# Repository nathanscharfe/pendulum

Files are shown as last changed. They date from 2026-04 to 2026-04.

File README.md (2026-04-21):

# Inverted Pendulum Optimal Control Demonstration

This project is a successful real-hardware optimal control demonstration for an inverted pendulum mounted to a linear actuator. The repository now includes hardware, modeling, firmware, host-side control software, and experimental results for repeatable upright balancing with an LQR-based controller.

The project was inspired by my `ASE 381P-3 Optimal Control` class with Dr. Bakolas at The University of Texas at Austin.

## Upright Balance Video

Watch on YouTube:

- https://youtu.be/KnxtTf5F7fo

Local fallback:

<video src="docs/media/upright_balance_run_2026-04-21.mp4" controls muted playsinline></video>

If your Markdown viewer does not render embedded video, open:

- `docs/media/upright_balance_run_2026-04-21.mp4`

This clip shows the current successful upright controller balancing the pendulum on real hardware.

## Run The Upright Control Test

From the repository root, run:

```powershell
python -m software.host.main --actuator-port COM6 --limits-port COM10 --encoder-port COM8 control-up
```

Or open the new UI workflow:

```powershell
python -m software.host.main control-up-ui
```

What to expect:

1. The cart homes left and then moves to the middle.
2. A staging prompt appears so you can operate the latch servo on Arduino #2:
   - `p` holds the pendulum with the servo at `80 deg`
   - `g` releases the servo to `0 deg`
   - `start` zeroes the encoder, sends `g`, and begins automatic control
3. Use the staging loop until the pendulum is aligned the way you want.
4. Type `start` to begin automatic control.
5. Keep clear and be ready to stop the run if needed.

Important notes:

- The angle at the moment you type `start` becomes the controller's zero reference, so careful manual alignment still matters.
- The current upright setup uses a latch servo on Arduino #2 (`D7`) so the pendulum can be staged before release.
- The repeatably working upright setup currently uses the default Python LQR upright settings with:
  - `pendulum-length-m = 0.50`
  - `Q = diag([1, 0.1, 50, 1])`
  - `R = 1`
- The most recent saved successful run is:
  - `hardware/control experiments/upright/successful_repeatable_upright_balance_20260421_113304.csv`
- The measured no-stall actuator ceiling was about `315 mm/s`, and the current upright default speed clamp is now `350 mm/s` for experimental testing.
- Output logs are written under `hardware/control experiments/upright/`.
- Analysis notebook: `hardware/control experiments/analysis/analyze_upright_control.ipynb`
- Each upright and downward control CSV now records the full run configuration, including `lqr_mode`, pendulum length, `Q`, `R`, resolved gains, clamps, estimator settings, trigger thresholds, and sign conventions as `config_*` columns.

## Run A Pendulum Period Test

From the repository root, run:

```powershell
python -m software.host.main --encoder-port COM8 period-test
```

What to expect:

1. The host opens the encoder serial port and tells you where the CSV will be written.
2. With the pendulum hanging motionless, press Enter to zero the resting angle and start recording.
3. Pull the pendulum back by a small angle and release it.
4. Let it swing freely for several periods.
5. Press Enter again to stop and save the CSV under `hardware/magnetic encoder/captures/`.

The resulting file includes both a host timestamp (`host_timestamp_s`) and the encoder board timestamp (`time_ms`) for each sample so the free-swing period can be estimated later from the logged angle trace. New captures are named `pendulum 1_period_test_*.csv`.

Analysis notebook:

- `hardware/magnetic encoder/analysis/analyze_pendulum_1_period_test.ipynb`

Current pendulum-1 validation result:

- Capture: `hardware/magnetic encoder/captures/pendulum 1_period_test_20260419_093442.csv`
- Average measured period: about `1.42 s`
- Simple-pendulum effective length estimate: about `0.50 m`
- This supports using an effective simple-pendulum length on the order of `0.50 m` for the current host-side control defaults.

## Project Goals

- Model the pendulum and linear actuator system.
- Identify useful system parameters from measurement and calibration data.
- Design an LQR controller for the linearized pendulum dynamics.
- Implement the control loop using a software interface such as LabVIEW, Python, MATLAB, or another suitable tool.
- Use an Arduino as the interface between the control software and the physical hardware.
- Compare real hardware behavior against the model and controller predictions.

## Hardware

Current bench hardware includes:

- Pendulum
- Linear actuator
- Arduino #1 for linear actuator stepper control
- Arduino #2 for optical actuator limit sensors
- Arduino #3 for AS5600 magnetic encoder angle sensing
- Position and/or angle sensors
- Computer running LabVIEW

Current hardware-related files:

- `docs/images/assembled_pendulum_bench_setup_2026-04-17.jpg`
- `hardware/linear actuator calibration/calibration_procedure.md`
- `hardware/linear actuator calibration/linear actuator speed calibration.xlsx`
- `hardware/linear actuator calibration/actuator_speed_fit.ipynb`
- `hardware/linear actuator calibration/host_travel_calibration_20260417_194546.csv`
- `hardware/linear actuator calibration/host_travel_calibration_results.md`
- `hardware/linear actuator calibration/calibrate_linear_actuator/calibrate_linear_actuator.ino`
- `hardware/linear actuator control/linear_actuator_controller/linear_actuator_controller.ino`
- `hardware/limit sensors/limit_sensor_reader/limit_sensor_reader.ino`
- `hardware/limit sensors/servo_angle_test/servo_angle_test.ino`
- `hardware/magnetic encoder/as5600_example/README.md`
- `hardware/magnetic encoder/pendulum_angle_reader/pendulum_angle_reader.ino`
- `hardware/cad/stl/arduino mount.stl`
- `hardware/cad/stl/bearing mount.stl`
- `hardware/cad/stl/encoder mount.stl`
- `hardware/cad/stl/pendulum hinge.stl`
- `hardware/cad/stl/weight attachment.stl`
- `hardware/cad/stl/weight attachment - threaded.stl`
- `hardware/cad/reference/linear actuator stage holes.jpg`

Current modeling and control files:

- `modeling/pendulum_actuator_derivation/README.md`
- `modeling/pendulum_actuator_derivation/docs/parameters.md`
- `modeling/pendulum_actuator_derivation/docs/inverted pendulum derivation.pdf`
- `modeling/pendulum_actuator_derivation/docs/torque_diagram.svg`
- `modeling/pendulum_actuator_derivation/scripts/lqr_first_pass.m`
- `modeling/pendulum_actuator_derivation/scripts/lqr_downward_first_pass.m`
- `modeling/pendulum_actuator_derivation/scripts/lqr_upright_length_qr_sweep.m`
- `modeling/pendulum_actuator_derivation/results/upright_first_pass/lqr_first_pass_results.md`
- `modeling/pendulum_actuator_derivation/results/upright_first_pass/LQR_closed_loop_response.fig`
- `modeling/pendulum_actuator_derivation/results/upright_first_pass/LQR_closed_loop_response.png`
- `modeling/pendulum_actuator_derivation/results/downward_first_pass/lqr_downward_first_pass_results.md`
- `modeling/pendulum_actuator_derivation/results/upright_length_qr_sweep/lqr_upright_length_qr_sweep_summary.csv`

Current host software files:

- `software/host/README.md`
- `software/host/requirements.txt`
- `software/host/main.py`
- `software/host/serial_worker.py`
- `software/host/arduino_actuator.py`
- `software/host/arduino_limits.py`
- `software/host/arduino_encoder.py`
- `software/host/motion_control.py`
- `software/host/travel_calibration.py`

The linear actuator calibration notebook fits the measured actuator data and gives a command equation for converting desired speed into the required delay:

```text
delay = 58399.75215056 / (speed + 0.00022846) - 3.82116746
```

The host-side travel calibration uses the measured raw-step travel scale:

```text
steps_per_mm = 10.652
position_mm = position_steps / 10.652
target_steps = round(target_mm * 10.652)
```

3D-printable solid model exports should go in:

- `hardware/cad/stl/`

Editable CAD source files, if used, should go in:

- `hardware/cad/source/`

CAD reference photos and measurements should go in:

- `hardware/cad/reference/`

## Software

Planned software stack:

- LabVIEW, Python, MATLAB, or another suitable tool for the main control interface and experiment workflow
- Arduino firmware split across three boards: actuator motion, limit sensors, and magnetic encoder sensing
- MATLAB, Python, or similar tools for modeling, simulation, and LQR design as needed

## Control Approach

The initial controller will be based on Linear Quadratic Regulator (LQR) design. The expected workflow is:

1. Derive or identify the system dynamics.
2. Linearize the model around the operating point of interest.
3. Choose state and input cost matrices.
4. Compute the LQR gain.
5. Test the controller in simulation.
6. Implement the controller through LabVIEW and Arduino.
7. Tune and validate on the physical system.

## Repository Structure

This repository is still being organized. A likely structure is:

```text
.
+-- hardware/
|   +-- cad/
|   |   +-- reference/  # CAD reference photos and measurements
|   |   +-- source/  # Editable CAD files
|   |   `-- stl/     # 3D-printable STL exports
|   +-- linear actuator calibration/
|   |   +-- actuator_speed_fit.ipynb
|   |   +-- calibration_procedure.md
|   |   +-- linear actuator speed calibration.xlsx
|   |   `-- calibrate_linear_actuator/
|   |       `-- calibrate_linear_actuator.ino
|   +-- linear actuator control/
|   |   `-- linear_actuator_controller/
|   |       +-- README.md
|   |       `-- linear_actuator_controller.ino
|   +-- limit sensors/
|   |   `-- limit_sensor_reader/
|   |       +-- README.md
|   |       `-- limit_sensor_reader.ino
|   `-- magnetic encoder/
|       +-- as5600_example/
|       |   `-- README.md
|       `-- pendulum_angle_reader/
|           +-- README.md
|           `-- pendulum_angle_reader.ino
+-- software/        # Control interface code, such as LabVIEW, Python, or MATLAB
+-- modeling/        # Models, simulations, and controller design scripts
`-- README.md
```

## Current Status

The project has moved well beyond initial setup and has now succeeded on hardware. The linear actuator speed calibration data has been collected, and a Python notebook now fits the calibration data to produce a desired-speed-to-delay command equation. The host-side raw-step travel calibration has been collected and gives a default scale of `10.652 steps/mm`. The Arduino sketch used for collecting the actuator speed calibration data is stored with the calibration files. Initial 3D-printable STL exports for the printed hardware have been added under `hardware/cad/stl/`, and the pendulum has been assembled with the printed parts. Both optical actuator limit sensors have been tested with Arduino inputs, and the Arduino #1 actuator controller firmware has been tested. The limit sensor reader firmware and magnetic encoder reader firmware are complete for the current three-Arduino setup, and Arduino #2 now also supports a simple latch-servo interface for upright staging. The actuator limit sensor wire harness has been built, and the magnetic encoder Arduino mount has been created. A first-pass point-mass inverted pendulum model has been derived, and MATLAB LQR simulations have been run for both inverted and downward equilibria. The Python host software now supports homing, absolute moves, encoder capture, period-test logging, downward control experiments, upright control experiments, experiment logging, analysis notebooks, a servo-assisted upright staging loop, and an interactive actuator acceleration sweep. A dedicated period test on pendulum 1 measured an average free-swing period of about `1.42 s`, which implies an effective simple-pendulum length of about `0.50 m`; that matches the current `0.500 m` host-side control default well. On hardware, the system now demonstrates repeatable upright balancing with the `0.50 m`, `Q = diag([1, 0.1, 50, 1])`, `R = 1` controller configuration shown above. Bench testing also established that the current actuator hardware can reliably reach about `315 mm/s` without stalling, while the present upright host defaults use more aggressive experimental speed and acceleration clamps for tuning work.

Current bench setup photo:

- `docs/images/assembled_pendulum_bench_setup_2026-04-17.jpg`

Project notes are tracked in:

- `docs/project_log.md`

## Next Steps

- Improve upright balance duration and reduce cart drift during inverted balancing runs.
- Make upright start-up more repeatable, including angle-zeroing workflow and mechanical alignment.
- Refine the encoder mounting and magnet alignment to reduce transient angle estimation errors.
- Revisit the upright model and LQR tuning after any pendulum geometry changes.
- Add better documentation for the experiment workflow, analysis notebooks, and best-known controller settings.
- Add editable CAD source files if they are available.

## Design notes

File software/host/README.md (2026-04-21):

# Host Software

Initial Python host-side project for communicating with the three-Arduino pendulum hardware setup.

GitHub issue: #7, `Set up initial host software project`

## Purpose

The host software starts one serial interface object for each Arduino:

- Arduino #1: linear actuator controller
- Arduino #2: optical limit sensor reader
- Arduino #3: AS5600 magnetic encoder reader

Each interface owns its serial port. Reader threads continuously collect serial data in the background and expose the latest parsed sample to the main script.

## Setup

Install Python dependencies:

```powershell
python -m pip install -r software\host\requirements.txt
```

## Run

Run with whichever Arduino ports are currently connected:

```powershell
python -m software.host.main --actuator-port COM3 --limits-port COM4 --encoder-port COM5
```

Current bench COM-port assignment:

- Arduino #1 actuator controller: `COM6`
- Arduino #2 limit sensor reader: `COM10`
- Arduino #3 AS5600 encoder reader: `COM8`

Current bench command:

```powershell
python -m software.host.main --actuator-port COM6 --limits-port COM10 --encoder-port COM8
```

Live bench smoke test:

- Date: 2026-04-17
- Command: `python -m software.host.main --actuator-port COM6 --limits-port COM10 --encoder-port COM8`
- Result: host successfully read actuator status, limit sensor state, and encoder angle data from all three Arduinos.
- Shutdown: `Ctrl+C` stopped the host monitor and sent a stop command to the actuator interface.

For an initial read-only test with only one Arduino connected, provide only that port:

```powershell
python -m software.host.main --encoder-port COM5
```

Optional flags:

- `--duration 10`: run for 10 seconds and exit.
- `--zero-encoder-on-start`: send `z` to the encoder Arduino after opening the port.
- `--poll-period 0.5`: print snapshots every 0.5 seconds.
- `--steps-per-mm 10.652`: override the actuator position scale.
- `--travel-mm 600`: override the assumed actuator travel.

## Basic Motion Commands

The host includes early motion commands with host-side limit-sensor checks. Current assumptions:

- Negative actuator motion moves toward the left limit.
- Positive actuator motion moves toward the right limit.
- The measured actuator travel calibration is `10.652 steps/mm`, or about `0.093879 mm/step`.
- The total travel estimate is about `600 mm` with the current limit sensor placement. Limit sensor physics can still make the observed limit-to-limit distance vary slightly by run.
- Arduino #1 receives raw step and step-rate commands. Millimeter conversion is handled on the host side.

Home left:

```powershell
python -m software.host.main --actuator-port COM6 --limits-port COM10 home --side left --speed-mm-s 25
```

Move to an absolute position after homing:

```powershell
python -m software.host.main --actuator-port COM6 --limits-port COM10 move-mm 300 --speed-mm-s 25
```

Move to the configured midpoint after homing:

```powershell
python -m software.host.main --actuator-port COM6 --limits-port COM10 middle --speed-mm-s 25
```

Move a relative number of raw steps:

```powershell
python -m software.host.main --actuator-port COM6 --limits-port COM10 move-steps 500 --steps-per-second 100
```

Move to an absolute raw step position:

```powershell
python -m software.host.main --actuator-port COM6 --limits-port COM10 goto-steps 2500 --steps-per-second 100
```

Run the interactive travel calibration routine:

```powershell
python -m software.host.main --actuator-port COM6 --limits-port COM10 calibrate-travel
```

Default calibration routine:

- Homes left.
- Prompts for the speed to run in steps/s.
- For each move length, `6000`, `5000`, `4000`, `3000`, `2000`, and `1000` steps:
  - returns to the 100-step start position
  - prompts for the tape measure reading at the 100-step start position
  - moves right by the requested step count
  - prompts for the tape measure reading after the move
- After a speed is complete, asks whether to run another speed or quit and save.
- Writes a CSV file under `hardware/linear actuator calibration/`.

Optional queued speeds can be supplied up front:

```powershell
python -m software.host.main --actuator-port COM6 --limits-port COM10 calibrate-travel --speeds 100 200 300
```

Calibration follow-up:

- GitHub issue: #21, `Run actuator travel calibration and fit step-to-mm conversion`
- An initial calibration attempt exposed a stale actuator-status issue after homing. The host now waits for Arduino #1 to confirm `position_steps = 0` after left homing before continuing.
- Empty CSV files from the interrupted attempts were not kept.

Important: opening the actuator Arduino serial port resets the Arduino, so `position_steps` is not preserved across separate Python invocations. For homing, moving, and checking position in one continuous session, use the interactive shell:

```powershell
python -m software.host.main --actuator-port COM6 --limits-port COM10 shell
```

Example shell session:

```text
motion> home left 10
motion> status
motion> middle 10
motion> move 50 10
motion> steps 500 100
motion> goto 2500 100
motion> status
motion> quit
```

Run a signed speed command for a fixed duration:

```powershell
python -m software.host.main --actuator-port COM6 --limits-port COM10 speed 20 --duration 2
```

Capture a free-swing pendulum encoder experiment:

```powershell
python -m software.host.main --encoder-port COM8 capture-encoder
```

The capture command waits for you to press Enter, zeros the current downward resting angle, records encoder data while you manually displace and release the pendulum, then stops when you press Enter again. Each run writes a timestamped CSV under `hardware/magnetic encoder/captures/`.

To keep the existing encoder zero instead:

```powershell
python -m software.host.main --encoder-port COM8 capture-encoder --no-zero-on-start
```

Open a lightweight live encoder UI:

```powershell
python -m software.host.main --encoder-port COM8 encoder-ui
```

This opens a small Tkinter window that uses the same live encoder stream as the control sessions, updates from the `100 Hz` serial samples, shows the latest `theta`, plots a rolling theta-vs-time trace, and includes a `Zero` button that sends the encoder zero command and clears the plotted history.

Run a dedicated small-angle pendulum period test:

```powershell
python -m software.host.main --encoder-port COM8 period-test
```

This command uses the same timestamped encoder logging path, but writes a `pendulum 1_period_test_*.csv` file and gives period-test-specific prompts so you can zero the hanging equilibrium, pull the pendulum back slightly, release it, and analyze the free oscillation later.

Current pendulum-1 check:

- Capture: `hardware/magnetic encoder/captures/pendulum 1_period_test_20260419_093442.csv`
- Analysis notebook: `hardware/magnetic encoder/analysis/analyze_pendulum_1_period_test.ipynb`
- Average measured period: about `1.42 s`
- Inferred simple-pendulum effective length: about `0.50 m`
- This is also close to the current `0.500 m` host-side control default, so the period-test estimate remains a reasonable working value.

Run a first-pass downward pendulum damping experiment:

```powershell
python -m software.host.main --actuator-port COM6 --limits-port COM10 --encoder-port COM8 control-down
```

Run a first-pass upright pendulum balancing experiment:

```powershell
python -m software.host.main --actuator-port COM6 --limits-port COM10 --encoder-port COM8 control-up
```

Open a UI for upright automatic control:

```powershell
python -m software.host.main control-up-ui
```

The upright-control UI uses the current bench defaults `COM6`, `COM10`, and `COM8` if ports are not provided. When it opens, it automatically connects to the three Arduinos, releases the latch for setup moves, homes left, moves to the midpoint, and then waits for you to press `Start Automatic Control`. The window includes:

- A live combined plot with filtered pendulum angle on the left axis and commanded cart speed on the right axis
- A `Start Automatic Control` button that zeros the encoder, releases the latch servo, and starts the balancing loop
- Real-time `Qx`, `Qx_dot`, `Qtheta`, `Qomega`, and `R` sliders that update the active Python-synthesized upright LQR gains while the controller is running
- A `Stop And Exit` button that stops the actuator and closes the UI

The downward command first homes left, then moves to the configured midpoint. Once the actuator is centered, let the pendulum hang downward and motionless, then press Enter to zero the encoder and start the damping loop. Press Enter again to stop the controller and write the log.

The upright command now uses a staging loop after the setup moves. Arduino #2 can drive a simple latch servo on `D7`, with:

- `p`: hold the pendulum with the servo at `80 deg`
- `g`: release the servo to `0 deg`
- `start`: zero the encoder, send `g`, and begin automatic control

This makes it possible to line up the upright start condition without rerunning the homing and midpoint move every time. `Ctrl+C`, active limit sensors, or exceeding the angle cutoff still stop the actuator and save the data.

The command uses the downward-equilibrium LQR gain from `lqr_downward_first_pass.m`:

```text
K = [0.3162, 0.8139, -0.3088, -0.3479]
```

The upright command uses the upright-equilibrium first-pass LQR gain from `lqr_first_pass.m`:

```text
K = [-1.0, -2.0104, -29.1450, -6.5238]
```

The host now computes these LQR gains directly in Python by default from the pendulum length and the requested `Q` and `R` weights, using the same linearized model as the MATLAB scripts. The default upright and downward settings reproduce the original first-pass MATLAB gains to numerical precision.

Useful control-synthesis arguments for `control-down` and `control-up`:

- `--lqr-mode python`: compute gains from `l`, `Q`, and `R` inside Python. This is now the default.
- `--lqr-mode manual`: bypass Python synthesis and use the explicit `--x-gain`, `--x-dot-gain`, `--theta-gain`, and `--omega-gain` values.
- `--pendulum-length-m 0.50`: change the modeled pendulum length without editing code. The current host default is `0.500 m`.
- `--q-x 1 --q-x-dot 0.1 --q-theta 50 --q-omega 1 --r-input 1`: change the LQR cost weights on demand.
- `--center-gain 0.2`: add an extra post-LQR cart-centering term in `1/s` if you want the cart to bias back toward track center.

Example upright command with a different pendulum length and custom `Q`, `R`:

```powershell
python -m software.host.main --actuator-port COM6 --limits-port COM10 --encoder-port COM8 control-up --pendulum-length-m 0.75 --q-x 1 --q-x-dot 0.1 --q-theta 80 --q-omega 2 --r-input 2
```

Because the upright first-pass LQR wants substantially more authority than the downward case, the upright command defaults to a larger acceleration and speed clamp:

- Control period: `0.01 s`
- Speed clamp: `+/-350 mm/s`
- Acceleration clamp: `+/-30.0 m/s^2`
- Control trigger: re-arm only after `|theta| > 0.015 rad` or `|theta_dot| > 0.08 rad/s` for `3` consecutive samples

The `350 mm/s` upright speed clamp is the current host default for upright testing. It is above the earlier measured no-stall `315 mm/s` baseline, so treat it as an experimental increase and back it off if the actuator shows signs of stalling.

Interactive actuator acceleration sweep:

```powershell
python -m software.host.main --actuator-port COM6 --limits-port COM10 accel-sweep --target-speed-mm-s 325 --accel-start-m-s2 4 --accel-stop-m-s2 20 --accel-step-m-s2 0.5 --command-period-s 0.01 --hold-duration-s 0.25
```

This command homes left before each trial, ramps the actuator from zero to the target speed using the requested acceleration, keeps the host-side limit checks active during the ramp, and asks whether the motor stalled before continuing to the next test acceleration.

It estimates the full state `[x, x_dot, theta, theta_dot]`, computes `u = -KX`, and integrates that acceleration command into the actuator step-rate interface. The command includes filtering, theta slew-rate limiting, and deadbands so a motionless pendulum does not make the actuator chatter.

Each control CSV now logs the full controller configuration on every row using `config_*` columns. That includes the selected LQR synthesis mode, pendulum length, `Q` and `R`, resolved gains, clamps, deadbands, trigger/disarm settings, estimator parameters, and sign conventions. The upright analysis notebook prints the active CSV path and summarizes those `config_*` fields near the top so each run can be interpreted without checking the terminal history.

Default controller behavior:

- Control period: `0.05 s`
- Speed clamp: `+/-150 mm/s`
- Acceleration clamp: `+/-0.5 m/s^2`
- Angle cutoff: `+/-0.35 rad`
- LQR cart-position gain: `0.3162`
- LQR cart-velocity gain: `0.8139`
- LQR theta gain: `-0.3088`
- LQR theta-dot gain: `-0.3479`
- Estimator: `alpha-beta`
- Alpha-beta angle gain: `0.35`
- Alpha-beta angular-rate gain: `0.04`
- Alpha-beta residual clamp: `0.01 rad`
- Armed alpha-beta angle gain: `0.40`
- Armed alpha-beta angular-rate gain: `0.06`
- Armed alpha-beta residual clamp: `0.025 rad`
- Theta deadband: `0.003 rad`
- Theta-dot deadband: `0.10 rad/s`
- Control trigger: `|theta| > 0.045 rad` or `|theta_dot| > 0.30 rad/s` for `2` consecutive samples
- Settle disarm: `|theta| < 0.03 rad` and `|theta_dot| < 0.15 rad/s` for `25` consecutive samples
- Theta slew-rate limit: `3.0 rad/s`
- Acceleration deadband: `0.005 m/s^2`
- Velocity leak: `0 1/s`
- Centering gain: `0 1/s`

If `--max-accel-m-s2` is set below the default acceleration deadband, the program automatically lowers the effective acceleration deadband to half of the acceleration clamp so commands are not silently zeroed.

Setup defaults:

- Home left speed: `50 mm/s`
- Move-to-middle speed: `50 mm/s`

To skip the setup moves for a repeat test:

```powershell
python -m software.host.main --actuator-port COM6 --limits-port COM10 --encoder-port COM8 control-down --no-home --no-middle
```

Each run writes a timestamped control CSV under `hardware/control experiments/downward/` or `hardware/control experiments/upright/`, plus sidecar raw sample logs for encoder, actuator, and limit-sensor serial data. Analysis notebooks live under `hardware/control experiments/analysis/`.

The hardware and model sign conventions are adjustable independently:

- `--invert-actuator-command`: flips the sign between the LQR acceleration command and physical actuator motion.
- `--invert-cart-position`: flips the sign of cart position and cart velocity before applying the LQR gain.
- `--invert-encoder-angle`: flips the sign of theta and theta-dot before applying the LQR gain.
- `--invert-control`: compatibility alias for `--invert-actuator-command`.

If a small perturbation gets worse instead of damping out, stop immediately and try the most likely sign change first. The latest bench runs suggest testing the actuator command and cart-position signs together:

```powershell
python -m software.host.main --actuator-port COM6 --limits-port COM10 --encoder-port COM8 control-down --invert-actuator-command --invert-cart-position
```

If the motion is too aggressive for a cautious retest, override the clamps with `--max-speed-mm-s` and `--max-accel-m-s2`.

The default `alpha-beta` estimator is intended to reject the several-degree encoder jumps seen when the pendulum is motionless while still estimating theta-dot with less lag than differentiating a heavily filtered angle. The controller also holds the actuator still until the estimated angle or angular rate exceeds a trigger threshold for several consecutive samples. After a perturbation damps back near zero, it disarms and zeros the speed command so the cart stops chasing encoder jitter. To fall back to the original filter path, use `--estimator legacy`. A more responsive test without making the controller react to every encoder count jump is:

```powershell
python -m software.host.main --actuator-port COM6 --limits-port COM10 --encoder-port COM8 control-down --invert-actuator-command --invert-cart-position --period-s 0.02
```

Initial live motion smoke test:

- Date: 2026-04-17
- Command: `python -m software.host.main --actuator-port COM6 --limits-port COM10 speed 5 --duration 1`
- Result: command worked as expected with host-side limit monitoring active.
- Direction check confirmed that positive speed moves away from the left limit and negative speed moves toward the left limit.
- Left-limit protection check: `python -m software.host.main --actuator-port COM6 --limits-port COM10 speed -5 --duration 30` correctly refused motion because the left limit was already active.
- Left homing check: `python -m software.host.main --actuator-port COM6 --limits-port COM10 home --side left --speed-mm-s 10` correctly set the actuator position estimate to zero while already at the left limit.
- Absolute move check: `python -m software.host.main --actuator-port COM6 --limits-port COM10 move-mm 50 --speed-mm-s 10` moved off the left limit and stopped as expected.
- Interactive shell workflow check: `home left 10`, `status`, `move 50 10`, `status`, `quit` worked in one continuous serial session. The final status reported `position_steps = 532` and `position_mm = 50.008`.
- After updating the host to disable the driver after completed `home` and `move` commands, the same shell workflow ended with `enabled = False`, `motion_mode = 0`, `position_steps = 532`, and `position_mm = 50.008`.
- Raw step shell check: `steps 100 100` increased `position_steps` from `0` to `100`, and `steps -100 100` returned `position_steps` to `0`. The displayed `position_mm` came from the provisional host-side step-to-mm conversion.

Stop immediately:

```powershell
python -m software.host.main --actuator-port COM6 stop
```

## Safety Note

The host motion commands are still bench-test utilities, not the final closed-loop controller. The host refuses to start motion into an already-active limit and stops motion if the limit in the active travel direction becomes active. Finite moves wait until the actuator firmware reports completion; use `Ctrl+C` in the shell or the `stop` command if a move needs to be interrupted.

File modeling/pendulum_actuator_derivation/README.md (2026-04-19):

# Pendulum-Actuator Model Derivation

This folder tracks the derivation for the initial state-space model of the pendulum mounted on the linear actuator.

GitHub issue: #20, `Derive initial pendulum-actuator state-space model`

## Goals

- Define the coordinate system and sign conventions.
- Choose the state vector and control input.
- Derive the equations of motion.
- Linearize the model around the selected operating point.
- Put the result in state-space form for LQR design.

## Working Assumptions

- The actuator carriage/base motion is horizontal.
- The pendulum is modeled as a rigid body.
- The first model may neglect bearing friction, actuator compliance, and sensor delay unless those effects are needed later.
- The actuator command can be represented initially by a base acceleration or an equivalent commanded motion input.

## Layout

This folder is organized into:

- `docs/` - shared derivation notes, parameter notes, and reference figures
- `scripts/` - MATLAB analysis scripts
- `results/` - generated figures, CSV summaries, and per-analysis notes

Shared modeling notes:

- `docs/parameters.md`
- `docs/inverted pendulum derivation.pdf`
- `docs/torque_diagram.svg`

MATLAB scripts:

- `scripts/lqr_first_pass.m` - upright-equilibrium LQR first pass
- `scripts/lqr_downward_first_pass.m` - downward-equilibrium LQR first pass for early bench damping tests
- `scripts/lqr_upright_length_qr_sweep.m` - upright-equilibrium sweep across pendulum length and several Q/R choices

Saved results:

- `results/upright_first_pass/lqr_first_pass_results.md`
- `results/upright_first_pass/LQR_closed_loop_response.fig`
- `results/upright_first_pass/LQR_closed_loop_response.png`
- `results/downward_first_pass/lqr_downward_first_pass_results.md`
- `results/downward_first_pass/LQR_downward_closed_loop_response.fig`
- `results/downward_first_pass/LQR_downward_closed_loop_response.png`
- `results/upright_length_qr_sweep/lqr_upright_length_qr_sweep_summary.csv`
- `results/upright_length_qr_sweep/lqr_upright_length_qr_sweep_theta.fig`
- `results/upright_length_qr_sweep/lqr_upright_length_qr_sweep_theta.png`
- `results/upright_length_qr_sweep/lqr_upright_length_qr_sweep_x.fig`
- `results/upright_length_qr_sweep/lqr_upright_length_qr_sweep_x.png`
- `results/upright_length_qr_sweep/lqr_upright_length_qr_sweep_tradeoffs.fig`
- `results/upright_length_qr_sweep/lqr_upright_length_qr_sweep_tradeoffs.png`

Recent parameter-validation notes:

- `hardware/magnetic encoder/captures/pendulum 1_period_test_20260419_093442.csv`
- `hardware/magnetic encoder/analysis/analyze_pendulum_1_period_test.ipynb`

The pendulum-1 free-swing period test gave an average period of about `1.42 s`, which corresponds to an effective simple-pendulum length of about `0.50 m`. That result is close to the `0.510 m` length already used in the first-pass MATLAB LQR scripts, so the original center-of-mass estimate remains a reasonable modeling value for now.

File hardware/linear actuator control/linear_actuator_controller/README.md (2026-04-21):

# Linear Actuator Controller Firmware

Arduino #1 firmware for commanding the linear actuator stepper driver.

## Wiring

- Driver `STEP` to Arduino `D10`
- Driver `DIR` to Arduino `D11`
- Driver `ENA` to Arduino `D12`
- Arduino `GND` to driver signal ground

## Driver DIP Switch Positions

Recorded bench setting for the linear actuator microstep driver:

```text
1: ON
2: OFF
3: OFF
4: OFF
5: OFF
6: OFF
```

If these switch positions change, actuator calibration and any tuned controller settings should be treated as invalid until rechecked.

The driver enable pin is treated as active-low:

```cpp
const byte ENABLE_ACTIVE_LEVEL = LOW;
const byte ENABLE_INACTIVE_LEVEL = HIGH;
```

## Serial Settings

- Baud: `115200`
- Commands end with a newline
- Commands can be separated with spaces or commas

## Commands

```text
h                         print help
?                         print status
e 1                       enable driver
e 0                       disable driver
x                         stop motion immediately
p <steps>                 set current position estimate
m <steps> <delay_us>      relative move by step count
r <steps_per_second>      continuous signed step-rate command
```

Examples:

```text
e 1
m 5000 100
m -5000 100
r 1000
r -1000
x
e 0
```

## Status Output

The firmware prints a status line every `500 ms`:

```text
status,time_ms,enabled,motion_mode,position_steps,remaining_move_steps,direction,step_delay_us
```

`motion_mode` values:

- `0`: idle
- `1`: relative move
- `2`: continuous motion

## Host-Side Unit Conversion

Arduino #1 accepts raw step commands and step-rate commands only. Physical-unit conversion, such as millimeters to steps or millimeters per second to steps per second, is handled by the host software.

## Safety Notes

- Arduino #1 does not read the limit sensors directly.
- The host software should monitor Arduino #2 limit sensor data and command Arduino #1 to stop before driving into an end stop.
- Use `x` for immediate software stop.
- Confirm direction signs with slow moves before running continuous commands.

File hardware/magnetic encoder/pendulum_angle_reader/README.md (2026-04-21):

# Pendulum Angle Reader Firmware

Arduino firmware for reading the pendulum angle from an AS5600 magnetic encoder.

Current bench hardware is an Arduino #3 connected to the AS5600 breakout over I2C.

## Requirements

- Arduino with I2C support
- AS5600 magnetic encoder breakout
- Rob Tillaart `AS5600` Arduino library

## Wiring

Current bench wiring from the AS5600 breakout to the Arduino:

- `VCC` to `5V`
- `GND` to `GND`
- `DIR` to `GND`
- `SCL` to `SCL`
- `SDA` to `SDA`

## Serial Output

The sketch streams CSV at `115200` baud:

```text
time_ms,connected,magnet_detected,magnet_too_weak,magnet_too_strong,agc,magnitude,raw_count,filtered_count,unwrapped_count,theta_deg,theta_rad,omega_rad_s
```

Ideal magnet-health flags are:

```text
connected = 1
magnet_detected = 1
magnet_too_weak = 0
magnet_too_strong = 0
```

During initial bring-up, the angle reading was smooth even though the magnetic field diagnostics reported `magnet_detected = 0` and `magnet_too_weak = 1`. For now, use the magnet fields as diagnostics rather than hard validity gates. Confirm that the angle is stable at rest, changes smoothly during rotation, wraps cleanly across `0/4095`, and returns to the same value at the same physical position.

Follow-up host captures on 2026-04-18 confirmed stable near-zero behavior, but larger manual angle checks were asymmetric. A roughly `45 deg` side-to-side check reported about `-47 deg` on one side and about `+89 deg` on the other. The likely cause is mechanical alignment: the magnet is currently sitting on the head of the pendulum axle bolt and may not be flat or centered relative to the AS5600. Before relying on the encoder for closed-loop control over a wider range, design a more stable magnet/sensor alignment method and repeat the held-angle validation.

## Serial Commands

- `z`: zero the current encoder position
- `r`: reset wrap tracking without changing the zero
- `h`: print the CSV header

## Notes

- The AS5600 angle registers are `0` to `4095` counts per revolution.
- `raw_count` is the unfiltered AS5600 raw angle register.
- `filtered_count` is the AS5600 filtered `ANGLE` register.
- The firmware now unwraps the filtered angle across the `0/4095` boundary so `theta_*` follows the chip's internal filter.
- `theta_deg` and `theta_rad` are reported relative to the current zero.
- `omega_rad_s` is a simple finite-difference estimate from the unwrapped angle.
- `agc` and `magnitude` are included so magnet field strength can be checked during bring-up.

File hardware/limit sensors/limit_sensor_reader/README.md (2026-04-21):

# Linear Actuator Limit Sensor Reader

Arduino firmware for the second Arduino that monitors the optical limit sensors at each end of the linear actuator.

Current bench hardware is an Arduino #2 that reads the two optical limit sensors and also drives the latch servo used for upright staging.

## Sensor Wiring

Current bench wiring from the sensors and latch servo to Arduino #2:

Left/end A limit sensor:

- `brown` to Arduino `5V`
- `blue` to Arduino `GND`
- `black` to Arduino `D2`
- `white` disconnected

Right/end B limit sensor:

- `brown` to Arduino `3.3V`
- `blue` to Arduino `GND`
- `black` to Arduino `D3`
- `white` disconnected

Latch servo:

- `black` to Arduino `GND`
- `red` to Arduino `VIN`
- `white` to Arduino `D7`

With the default sketch settings, `left_limit` and `right_limit` should change between `0` and `1` when each sensor is unblocked and blocked.

## Sketch Pin Settings

- Left/end A black signal: `D2`
- Right/end B black signal: `D3`
- Latch servo signal: `D7`
- Left/end A white complement signal: disabled by default
- Right/end B white complement signal: disabled by default

If the white complement wires are used, enable them by assigning Arduino input pins:

```cpp
const byte LEFT_LIMIT_COMPLEMENT_PIN = 4;
const byte RIGHT_LIMIT_COMPLEMENT_PIN = 5;
```

## Input Polarity

The sketch defaults to:

```cpp
const byte LIMIT_INPUT_MODE = INPUT_PULLUP;
const byte LIMIT_ACTIVE_LEVEL = LOW;
```

That matches the tested sensors: the black signal wire uses the Arduino internal pullup, and a blocked beam reads active.

If the readings are backwards, change:

```cpp
const byte LIMIT_ACTIVE_LEVEL = HIGH;
```

## Serial Output

The sketch streams CSV at `115200` baud:

```text
time_ms,left_limit,right_limit,left_complement,right_complement,left_pair_ok,right_pair_ok,any_limit
```

It also prints event lines when a main limit state changes:

```text
# event,time_ms,left_limit,active
# event,time_ms,right_limit,inactive
```

## Serial Commands

- `h`: print the CSV header
- `s`: print the current state immediately
- `g`: release the servo to `0 deg`
- `p`: hold the servo at `80 deg`

## Bring-Up Checklist

- Trigger each end by hand and confirm the matching CSV field changes.
- Confirm the complement signal is opposite the main signal if the white wire is used.

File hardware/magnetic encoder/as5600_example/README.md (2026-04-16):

# AS5600 Magnetic Encoder Example

Use this folder for the first Arduino example sketch that reads the AS5600 magnetic encoder.

Example sketch location:

- `hardware/magnetic encoder/as5600_example/AS5600_demo/AS5600_demo.ino`

Record the wiring, Arduino board, library version, and any calibration notes here after the example code is tested.

If the sketch prints only `0    0` for the angle readings, first check that the code is using `AS5600 as5600;` for a standard AS5600 board instead of `AS5600L as5600;`. Most AS5600 breakout boards use I2C address `0x36`; the AS5600L variant is a different address-programmable part.

The diagnostic sketch in `AS5600_demo/AS5600_demo.ino` prints:

- `connected`: whether the chip responds on I2C
- `detectMagnet`: whether the AS5600 sees the magnet
- `tooWeak`: whether the magnetic field is too weak
- `tooStrong`: whether the magnetic field is too strong
- `AGC`: the chip's automatic gain setting
- `magnitude`: the measured magnetic field magnitude
- `angle` and `rawAngle`: encoder output counts

Bring-up result: the test setup connected over I2C and returned smooth angle readings, but the status bits reported `detectMagnet = 0` and `tooWeak = 1`. The observed diagnostic values included `AGC = 255` and magnitude around `279`. For control work, the most important check is whether `rawAngle` is stable at rest and sweeps smoothly through `0` to `4095` as the shaft rotates. Treat the magnet status bits as diagnostics until the final magnet and shaft geometry are installed.

## Notes To Fill In

- Arduino board:
- AS5600 breakout/module:
- Supply voltage:
- I2C pins:
- Library used:
- Magnet orientation notes:
- Raw output range:
- Angle direction convention:

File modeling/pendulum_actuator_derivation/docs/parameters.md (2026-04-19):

# Pendulum-Actuator Model Parameters

GitHub issue: #20, `Derive initial pendulum-actuator state-space model`

## Initial Point-Mass Model

For the first LQR model, treat the pendulum as a point mass located at the rough center of mass of the bob.

Measured pendulum length:

\[
l = 510\ \text{mm} = 0.510\ \text{m}
\]

Measurement definition:

- \(l\) is measured from the pendulum pivot to the rough center of mass of the bob.
- The current pendulum uses an available dowel, so this length is an initial hardware value rather than an optimized design choice.
- Later design iterations may change the pendulum length if simulations or hardware tests show that a longer or shorter pendulum would work better.

Period-test cross-check:

- `hardware/magnetic encoder/captures/pendulum 1_period_test_20260419_093442.csv`
- `hardware/magnetic encoder/analysis/analyze_pendulum_1_period_test.ipynb`
- Average measured free-swing period: about `1.42 s`
- Inferred simple-pendulum effective length: about `0.500 m = 500 mm`

This period-based estimate is within about `10 mm` of the original `510 mm` tape-measure estimate, so the first-pass LQR model parameter remains consistent with the current hardware measurement.

Gravity:

\[
g = 9.81\ \text{m/s}^2
\]

Actuator travel:

\[
x_{\text{travel,total}} \approx 0.60\ \text{m}
\]

If the actuator starts near the center of travel, the approximate one-sided travel available is:

\[
x_{\text{travel,one-side}} \approx 0.30\ \text{m}
\]

## Initial Linearized Model Coefficients

Using the simplified point-mass model with actuator acceleration input \(u = \ddot{x}\):

\[
A_{4,3} = \frac{g}{l}
\]

\[
B_4 = -\frac{1}{l}
\]

With \(l = 0.510\ \text{m}\):

\[
\frac{g}{l} = \frac{9.81}{0.510} \approx 19.235\ \text{s}^{-2}
\]

\[
-\frac{1}{l} = -\frac{1}{0.510} \approx -1.961\ \text{m}^{-1}
\]

These coefficients are for the first-pass MATLAB/LQR simulation. A later compound-pendulum model may replace \(l\) with measured mass, center-of-mass distance, and moment of inertia terms.

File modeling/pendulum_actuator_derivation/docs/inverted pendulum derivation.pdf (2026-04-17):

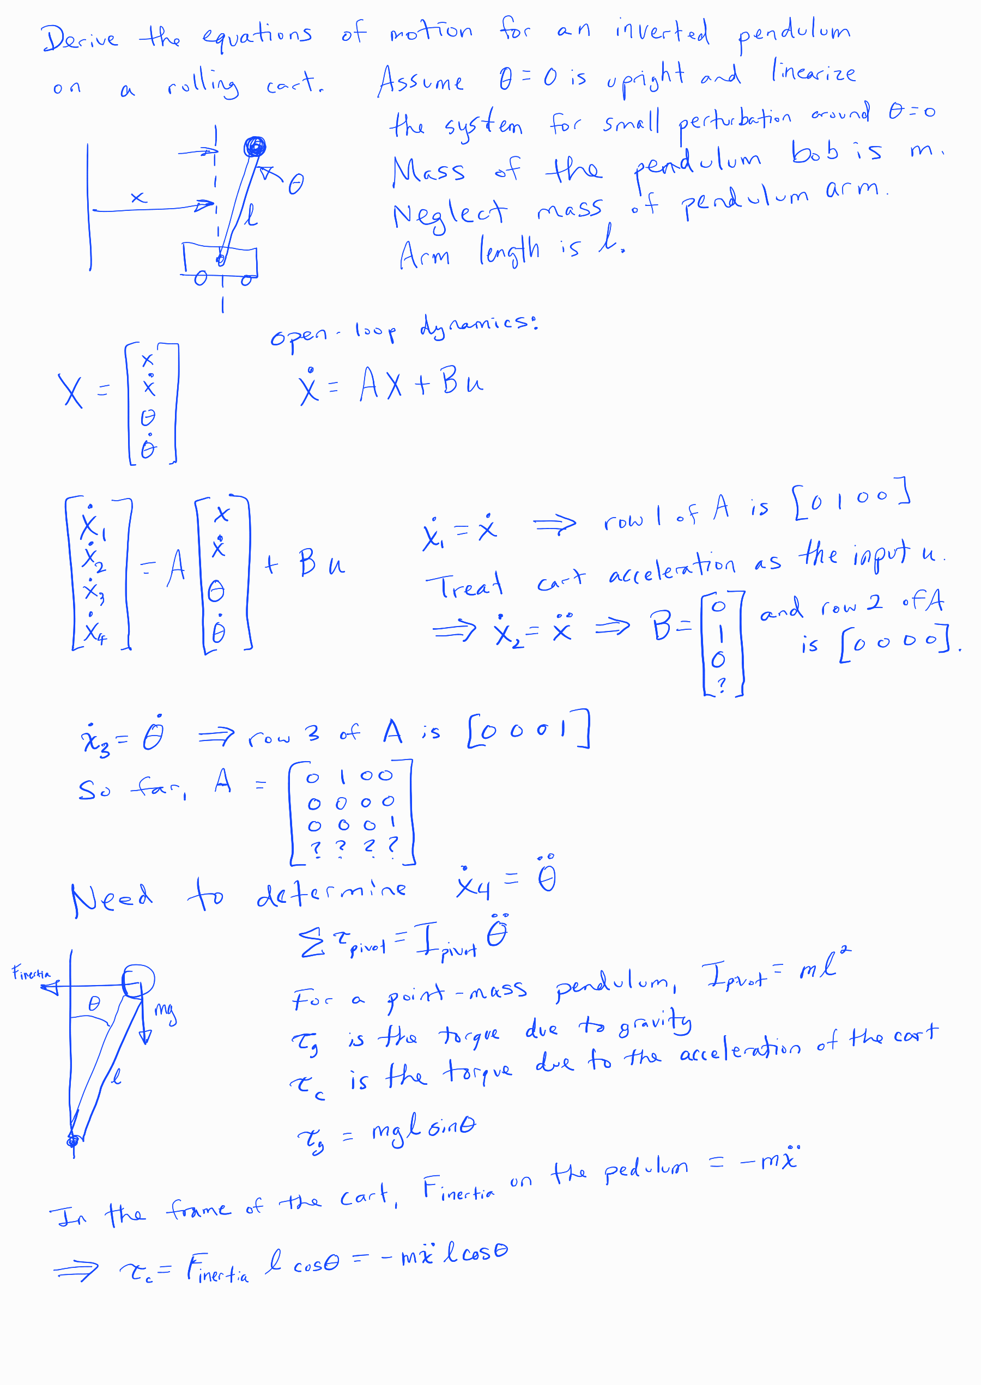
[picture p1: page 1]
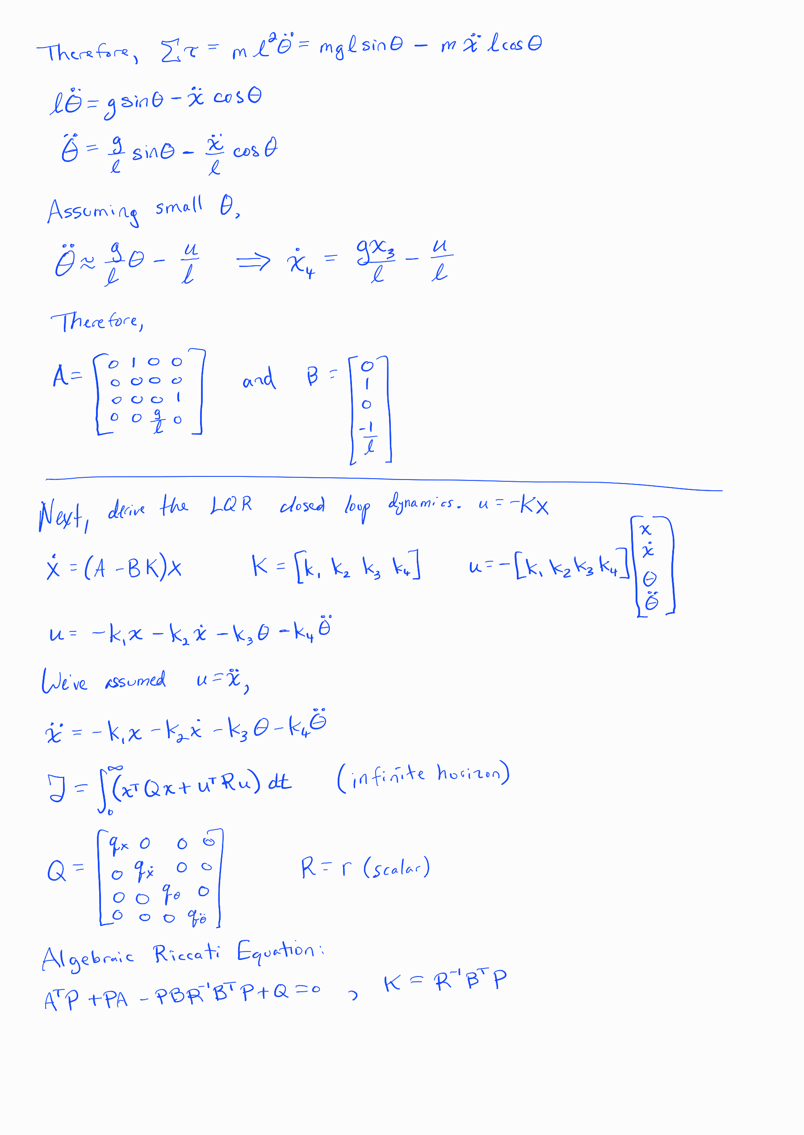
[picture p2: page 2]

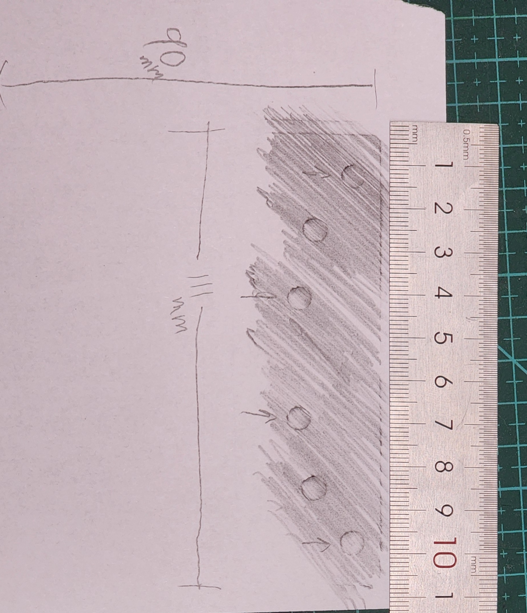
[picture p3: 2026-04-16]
hardware/cad/reference/linear actuator stage holes.jpg

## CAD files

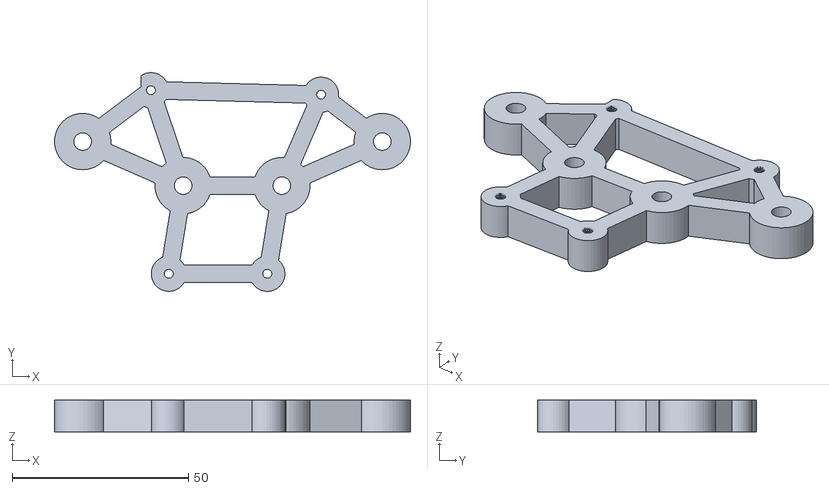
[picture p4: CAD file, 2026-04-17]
hardware/cad/stl/arduino mount.stl
101.0 x 62.1 x 9.00

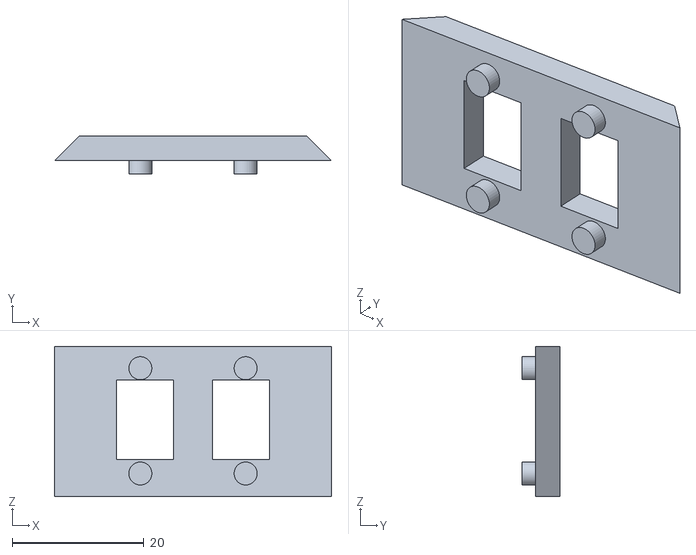
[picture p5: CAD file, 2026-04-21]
hardware/cad/stl/gen 2/encoder stage Z.stl
42.1 x 5.74 x 22.8

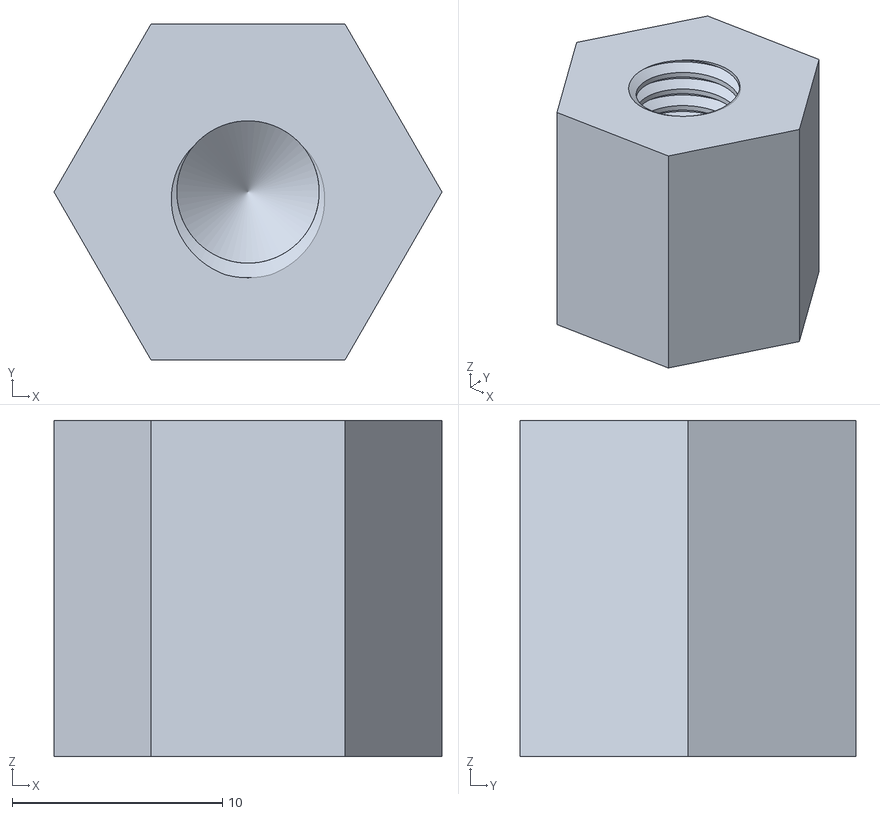
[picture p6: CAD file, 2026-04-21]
hardware/cad/stl/gen 2/magnet holder.stl
18.5 x 16.0 x 16.0

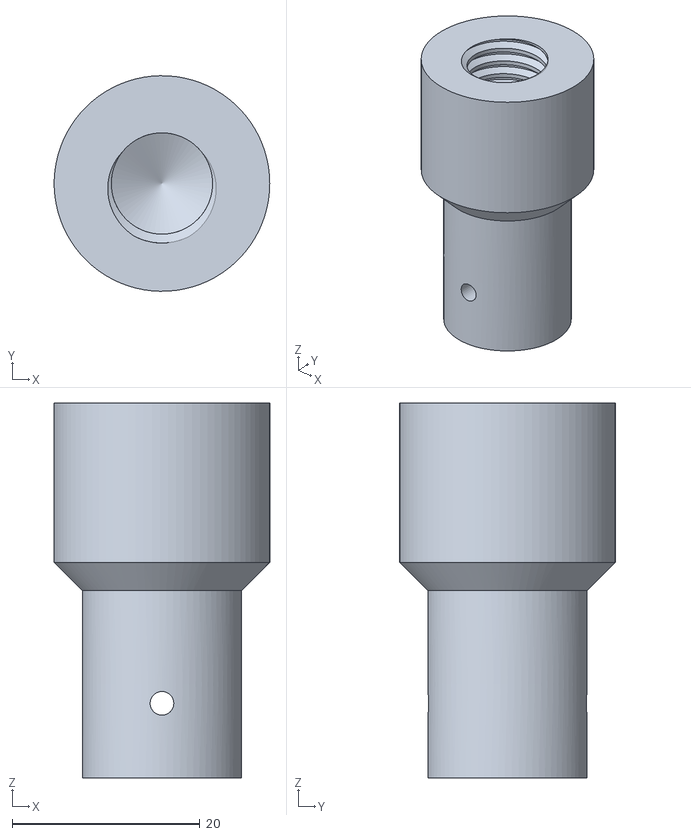
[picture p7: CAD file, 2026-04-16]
hardware/cad/stl/weight attachment - threaded.stl
23.0 x 23.0 x 40.0

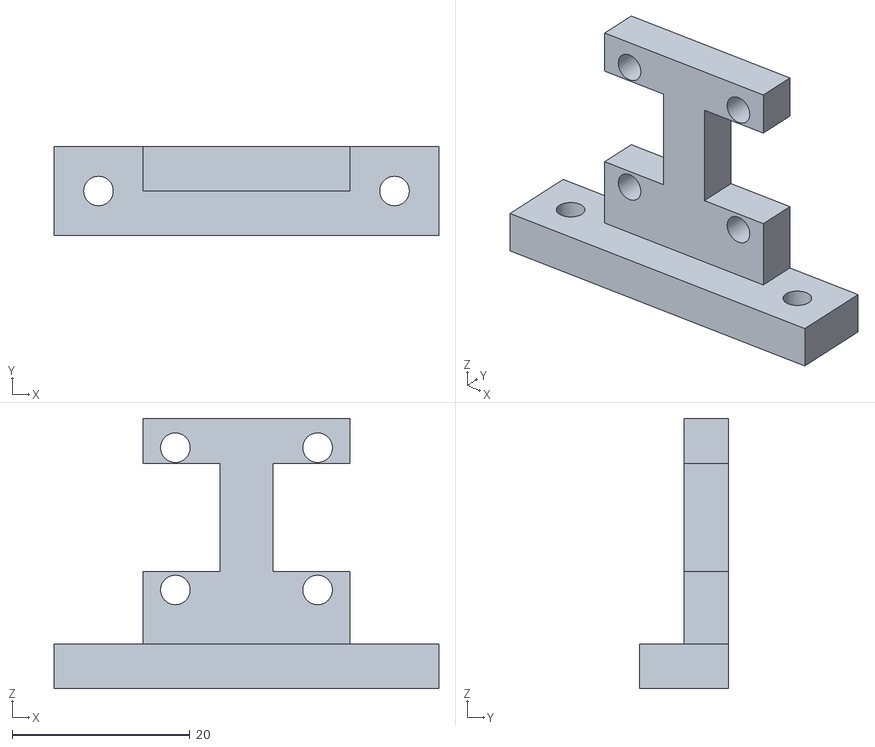
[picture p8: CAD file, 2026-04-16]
hardware/cad/stl/encoder mount.stl
43.3 x 10.0 x 30.4

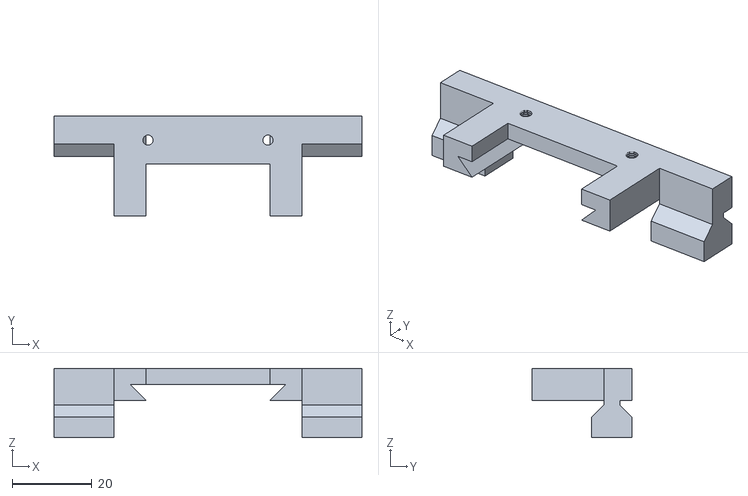
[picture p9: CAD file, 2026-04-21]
hardware/cad/stl/gen 2/encoder stage X.stl
77.0 x 25.0 x 17.3

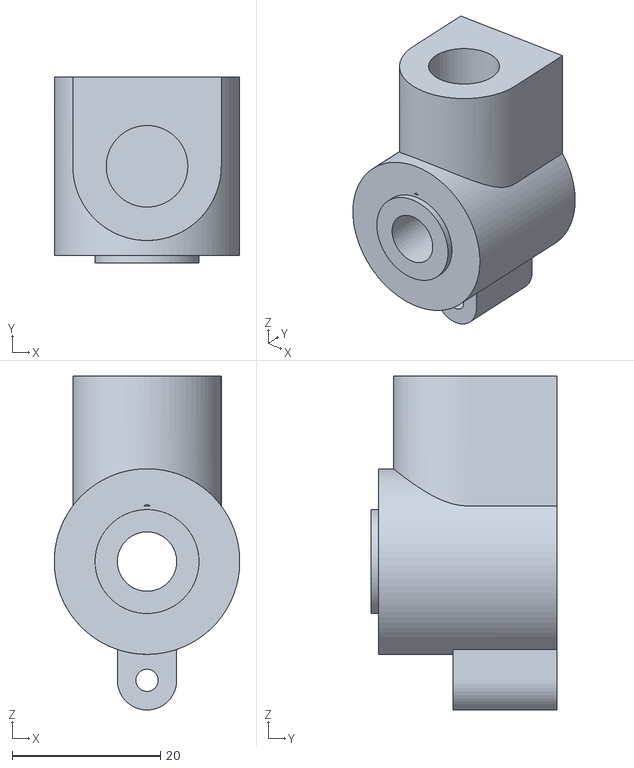
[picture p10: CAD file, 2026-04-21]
hardware/cad/stl/gen 2/pendulum hub 11mm.stl
25.0 x 25.0 x 45.0

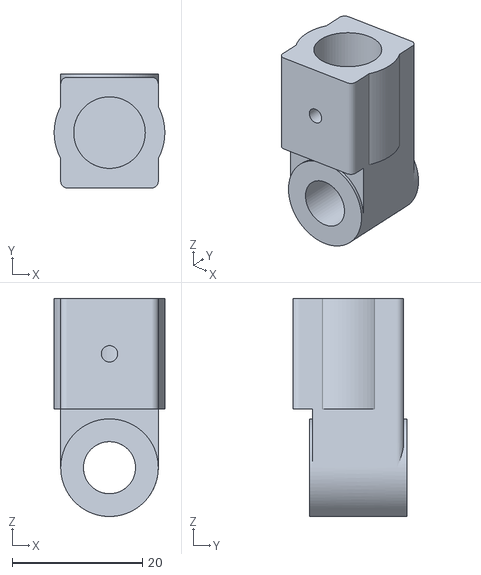
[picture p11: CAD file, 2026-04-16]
hardware/cad/stl/pendulum hinge.stl
17.0 x 17.5 x 33.5

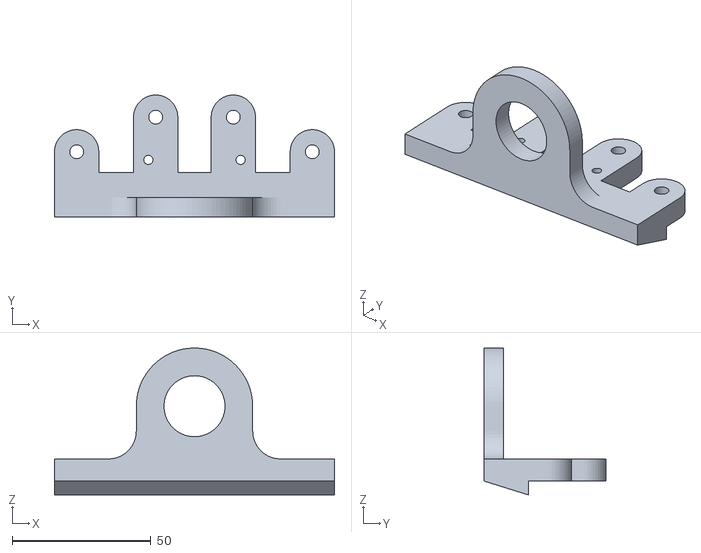
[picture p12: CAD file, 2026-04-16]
hardware/cad/stl/bearing mount.stl
101.0 x 44.0 x 53.0

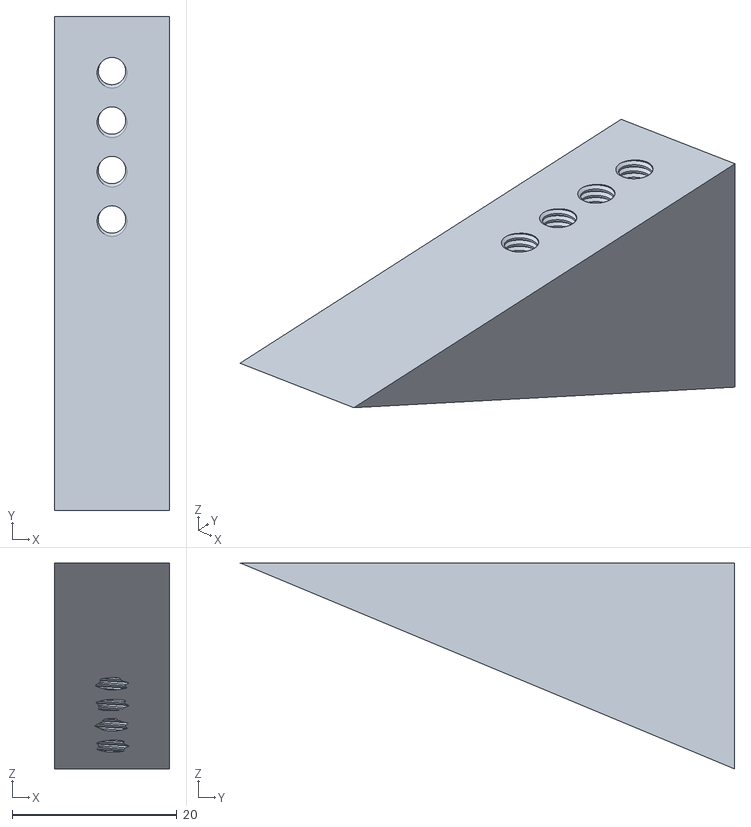
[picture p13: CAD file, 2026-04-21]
hardware/cad/stl/gen 2/stage adapter support.stl
14.0 x 60.0 x 25.0

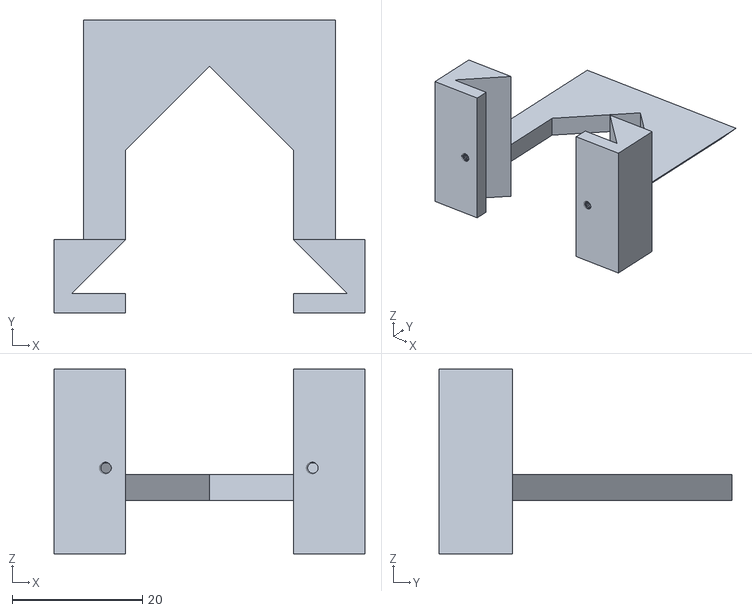
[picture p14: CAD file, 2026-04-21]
hardware/cad/stl/gen 2/encoder stage Y.stl
47.8 x 45.0 x 28.4

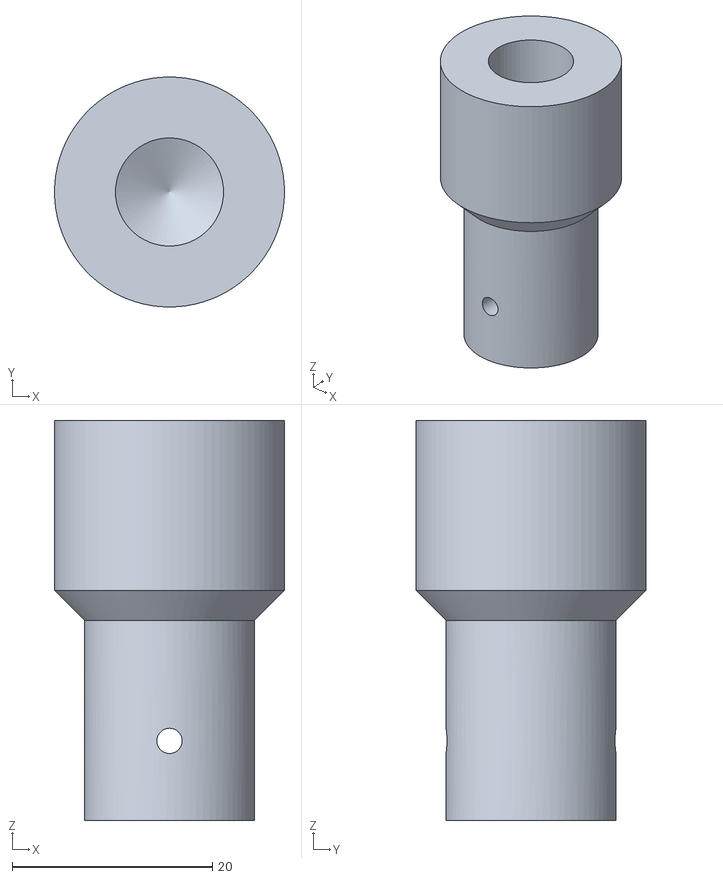
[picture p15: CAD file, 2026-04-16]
hardware/cad/stl/weight attachment.stl
23.0 x 23.0 x 40.0

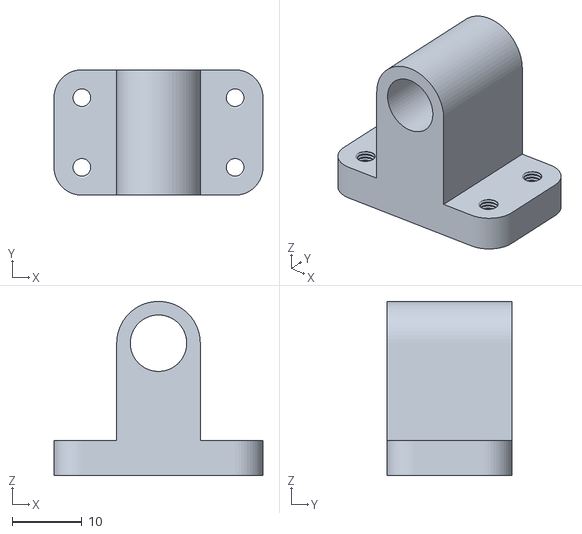
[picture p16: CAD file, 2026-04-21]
hardware/cad/stl/gen 2/plastic bearing.stl
30.0 x 18.0 x 25.0

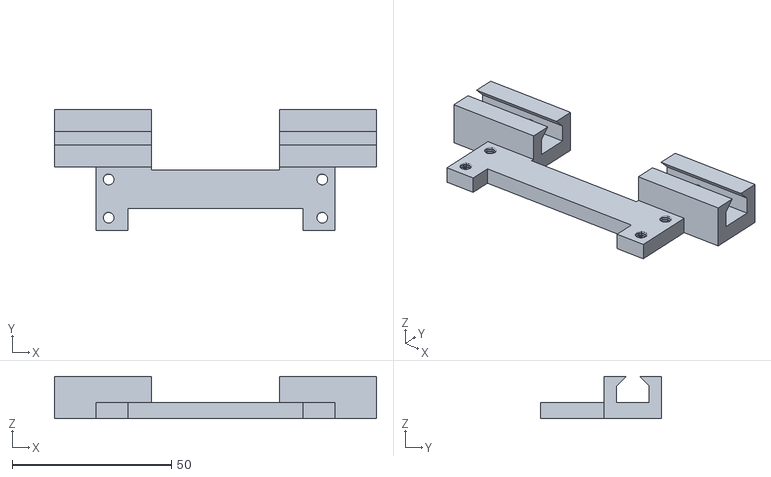
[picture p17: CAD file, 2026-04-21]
hardware/cad/stl/gen 2/encoder stage base.stl
101.0 x 38.0 x 13.2

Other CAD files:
hardware/cad/stl/gen 2/encoder stage.stl
hardware/cad/stl/gen 2/servo mount.stl
hardware/cad/stl/gen 2/encoder stage mount.stl
hardware/cad/stl/gen 2/weight holder.step
hardware/cad/stl/gen 2/arduino mount.f3d
hardware/cad/stl/gen 2/encoder mount.f3d
hardware/cad/stl/gen 2/encoder mount.stl
hardware/cad/stl/gen 2/encoder stage mount.f3d
hardware/cad/stl/gen 2/encoder stage.f3d
hardware/cad/stl/gen 2/magnet holder.f3d
hardware/cad/stl/gen 2/pendulum center.f3d
hardware/cad/stl/gen 2/pendulum center.stl
hardware/cad/stl/gen 2/pillow block.f3d
hardware/cad/stl/gen 2/pillow block.stl
hardware/cad/stl/gen 2/stage adapter support.f3d
hardware/cad/stl/gen 2/stage adapter.f3d
hardware/cad/stl/gen 2/stage.f3d
hardware/cad/stl/gen 2/weight attachment.f3d
hardware/cad/stl/gen 2/weight attachment.stl
hardware/cad/stl/gen 2/weight holder2.stl

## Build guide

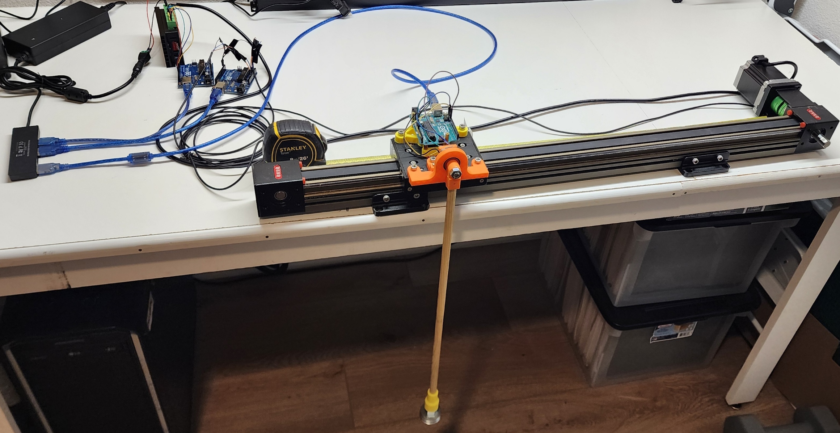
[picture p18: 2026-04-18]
docs/images/assembled_pendulum_bench_setup_2026-04-17.jpg

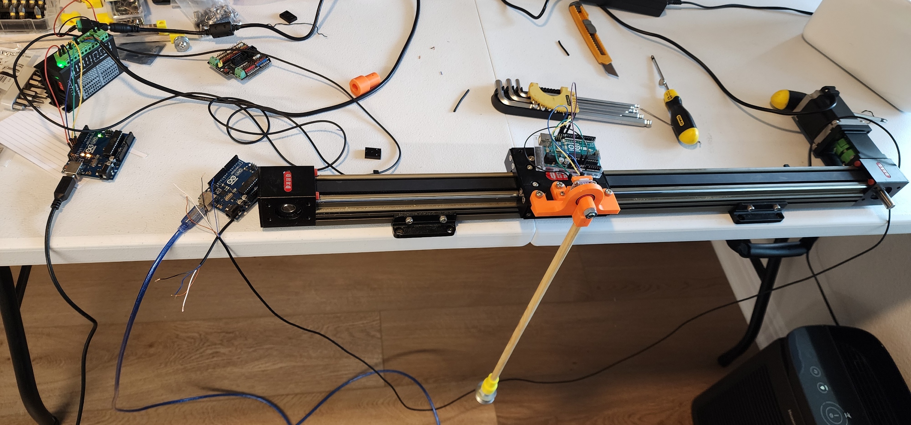
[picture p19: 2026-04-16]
docs/images/assembled_pendulum_bench_setup_2026-04-16.jpg

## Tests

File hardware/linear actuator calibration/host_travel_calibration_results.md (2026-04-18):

# Host Travel Calibration Results

Date: 2026-04-17

Raw data:

- `host_travel_calibration_20260417_194546.csv`

The host travel calibration returned to the 100-step reference position before each move. The tape reading at the 100-step reference was `599 mm` for every row. Positive actuator motion moved away from the left limit and decreased the tape reading, so the measured travel was calculated as:

```text
travel_mm = start_tape_reading_mm - tape_reading_mm
```

## Measurements

| Speed (steps/s) | Commanded steps | Start reading (mm) | End reading (mm) | Travel (mm) | Steps/mm |
| ---: | ---: | ---: | ---: | ---: | ---: |
| 400 | 6000 | 599.0 | 35.5 | 563.5 | 10.6477 |
| 400 | 5000 | 599.0 | 129.5 | 469.5 | 10.6496 |
| 400 | 4000 | 599.0 | 223.5 | 375.5 | 10.6525 |
| 400 | 3000 | 599.0 | 317.5 | 281.5 | 10.6572 |
| 400 | 2000 | 599.0 | 411.5 | 187.5 | 10.6667 |
| 400 | 1000 | 599.0 | 505.0 | 94.0 | 10.6383 |

## Average Scale

Average measured scale:

```text
steps_per_mm = 10.651997690950955
mm_per_step = 0.09387916666666667
```

Use the rounded host calibration value:

```text
steps_per_mm = 10.652
position_mm = position_steps / 10.652
target_steps = round(target_mm * 10.652)
```

This is very close to the earlier provisional calibration of `5000 steps / 470 mm = 10.638 steps/mm`, but the new value is based on the repeated raw-step travel measurements collected by the host calibration routine.

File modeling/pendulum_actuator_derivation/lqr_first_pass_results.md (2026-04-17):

# First-Pass LQR Simulation Results

GitHub issue: #20, `Derive initial pendulum-actuator state-space model`

Simulation script:

- `lqr_first_pass.m`

Saved response figure:

- `LQR_closed_loop_response.fig`
- `LQR_closed_loop_response.png`

## Model

The simulation used the simplified point-mass model with actuator acceleration input:

\[
u = \ddot{x}
\]

State vector:

\[
X =
\begin{bmatrix}
x \\
\dot{x} \\
\theta \\
\dot{\theta}
\end{bmatrix}
\]

Measured pendulum length:

\[
l = 0.510\ \text{m}
\]

## LQR Weights

\[
Q = \operatorname{diag}(1,\ 0.1,\ 50,\ 1)
\]

\[
R = 1
\]

## MATLAB Output

LQR gain:

\[
K =
\begin{bmatrix}
-1.0000 & -2.0104 & -29.1450 & -6.5238
\end{bmatrix}
\]

Closed-loop eigenvalues:

\[
\lambda(A-BK) =
\begin{bmatrix}
-4.7376 + 1.1311i \\
-4.7376 - 1.1311i \\
-0.6531 + 0.6199i \\
-0.6531 - 0.6199i
\end{bmatrix}
\]

Simulation summary:

- Peak commanded acceleration: \(2.543\ \text{m/s}^2\)
- Peak cart displacement: \(0.228\ \text{m}\)
- Approximate total actuator travel: \(0.60\ \text{m}\)
- Approximate one-sided travel from center: \(0.30\ \text{m}\)

## Notes

- All closed-loop eigenvalues have negative real parts, so the linearized closed-loop system is stable for this first-pass controller.
- The angle response settles back toward upright from the tested initial perturbation.
- The peak cart displacement is about \(0.228\ \text{m}\). With approximately \(0.30\ \text{m}\) one-sided travel from actuator center, this first simulation stays inside the nominal travel range but leaves limited margin.
- The peak commanded acceleration is about \(2.543\ \text{m/s}^2\). This should be compared against what the actuator can actually produce with the stepper driver and current command interface.

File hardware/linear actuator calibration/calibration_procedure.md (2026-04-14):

# Linear Actuator Calibration Procedure

This procedure describes how the linear actuator speed calibration data was collected.

## Purpose

The goal of this calibration is to estimate the relationship between the commanded step delay and the resulting actuator speed. The fitted relationship is used to convert a desired actuator speed into the delay value needed by the Arduino stepper motor control code.

## Hardware Setup

The calibration setup used:

- Linear actuator
- Microstep driver
- Arduino
- External power source for the actuator/driver
- Basic Arduino stepper motor demo code for initial motion testing
- Calibration Arduino sketch:
  - `calibrate_linear_actuator/calibrate_linear_actuator.ino`

## Procedure

1. Set up the linear actuator, microstep driver, Arduino, and power source.
2. Use a basic Arduino stepper motor demo file to command the actuator to move `5000` steps.
3. Benchmark the physical distance traveled during the `5000` step move.
4. Use the calibration Arduino file to run repeated `5000` step moves at different delay values.
5. Record the number of milliseconds required for each `5000` step run.
6. Record the measured travel distance, command delay values, elapsed times, and calculated speeds in the Excel calibration file:
   - `linear actuator speed calibration.xlsx`
7. Use the calibration notebook to fit the measured data:
   - `actuator_speed_fit.ipynb`

## Calibration Data

The Excel file stores the measured data used for the fit. The key columns are:

- `speed`: calculated actuator speed for the run
- `delay`: command delay used by the Arduino stepper control code
- `ms`: measured elapsed time for the `5000` step move

The calibration sheet also records:

- Travel distance: `470 mm`
- Commanded move: `5000 steps`

## Fitted Command Equation

The notebook fits the calibration data and provides this command equation:

```text
delay = 58399.75215056 / (speed + 0.00022846) - 3.82116746
```

Use this equation to convert a desired actuator speed into the delay value sent to the Arduino.

## Notes

- The equation should only be trusted over the speed and delay range covered by the calibration data.
- If the actuator, driver settings, power supply, load, belt drive, or microstepping settings change, the calibration should be repeated.
- The calibration data was collected using `5000` step moves, so future verification tests should start with the same move length before changing the test setup.

## Calibration Setup Photo

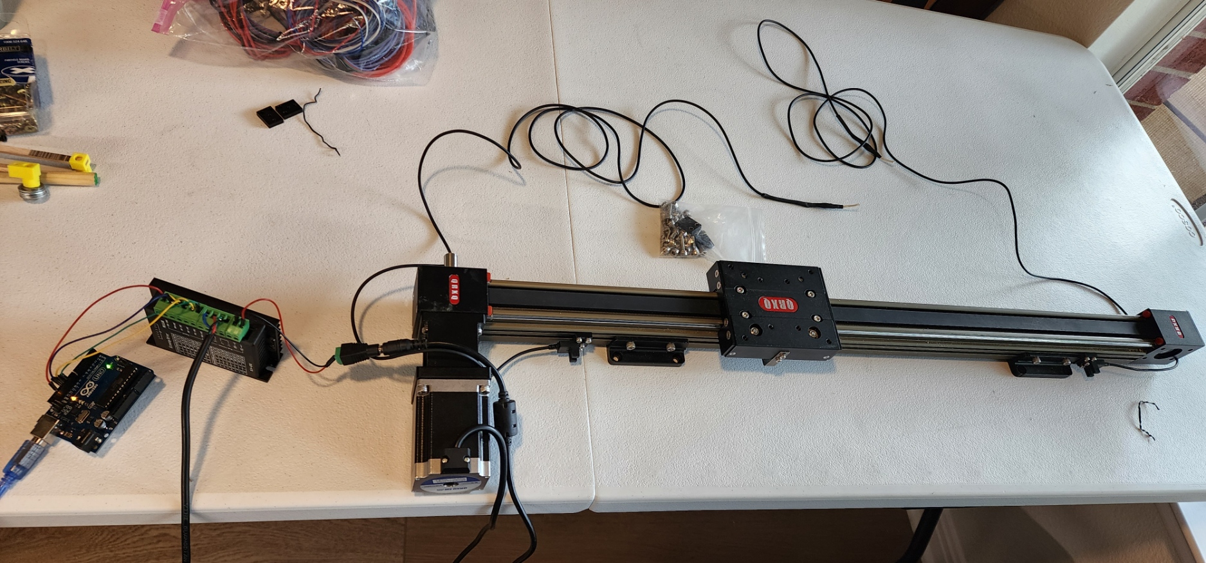
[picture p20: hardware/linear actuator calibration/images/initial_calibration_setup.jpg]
Initial linear actuator calibration setup


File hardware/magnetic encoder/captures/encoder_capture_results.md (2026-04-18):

# Magnetic Encoder Capture Results

Bench captures collected with:

```powershell
python -m software.host.main --encoder-port COM8 capture-encoder
```

## 2026-04-18 Captures

Raw capture files:

- `encoder_capture_20260418_112254.csv`
- `encoder_capture_20260418_113008.csv`
- `encoder_capture_20260418_113607.csv`

Summary:

- The host capture workflow recorded AS5600 data at about `100 Hz`.
- The encoder stayed connected throughout the reviewed captures.
- Near the downward resting position, the angle returned close to zero with roughly one-count quantization noise.
- The AS5600 magnetic diagnostics continued to report a weak field:
  - `magnet_detected = 0` for most or all samples
  - `magnet_too_weak = 1`
  - `agc = 255`
- Larger manual angle checks showed asymmetric angle response:
  - A roughly `90 deg` manual side-to-side check reported about `-89 deg` on one side and about `+150 deg` on the other.
  - A roughly `45 deg` manual side-to-side check reported about `-47 deg` on one side and about `+89 deg` on the other.
- The magnitude value changed substantially with angle, which suggests the current magnet/chip geometry is not well centered or planar.

Interpretation:

The host software capture path is working, and the encoder is stable near the downward rest position. The main remaining risk is mechanical: the magnet is currently sitting on the head of the pendulum axle bolt, so it may be tilted or off-center relative to the AS5600. A more dimensionally stable magnet holder and sensor alignment feature should be designed before trusting the encoder angle over the full control range.

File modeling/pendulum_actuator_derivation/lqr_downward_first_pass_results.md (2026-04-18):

# First-Pass Downward LQR Simulation Results

Simulation script:

- `lqr_downward_first_pass.m`

Saved response figure:

- `LQR_downward_closed_loop_response.fig`
- `LQR_downward_closed_loop_response.png`

## Model

The simulation used the same simplified point-mass model as the upright first pass, with actuator acceleration input:

\[
u = \ddot{x}
\]

State vector:

\[
X =
\begin{bmatrix}
x \\
\dot{x} \\
\theta \\
\dot{\theta}
\end{bmatrix}
\]

For this downward-equilibrium controller, \(\theta = 0\) is the hanging-down position.

Measured pendulum length:

\[
l = 0.510\ \text{m}
\]

## Linearized Downward Model

Compared with the upright model, the gravity stiffness term changes sign because gravity is restoring about the downward equilibrium:

\[
A_{4,3} = -\frac{g}{l}
\]

The input matrix keeps the same base-acceleration sign convention:

\[
B_4 = -\frac{1}{l}
\]

## LQR Weights

\[
Q = \operatorname{diag}(1,\ 0.1,\ 5,\ 1)
\]

\[
R = 10
\]

These weights are deliberately gentler than the upright first-pass controller because the downward pendulum is already passively stable.

## MATLAB Output

Downward LQR gain:

\[
K =
\begin{bmatrix}
0.3162 & 0.8139 & -0.3088 & -0.3479
\end{bmatrix}
\]

Closed-loop eigenvalues:

\[
\lambda(A-BK) =
\begin{bmatrix}
-0.3478 + 4.3777i \\
-0.3478 - 4.3777i \\
-0.4002 + 0.3940i \\
-0.4002 - 0.3940i
\end{bmatrix}
\]

Simulation summary:

- Peak commanded acceleration: \(0.112\ \text{m/s}^2\)
- Peak cart displacement: \(0.027\ \text{m}\)

## Notes

- The response is lightly damped, which is expected for a conservative controller around the naturally stable downward equilibrium.
- The angle oscillates and decays toward the downward equilibrium over the simulated `12 s` window.
- The required cart displacement and acceleration are much smaller than the upright first-pass simulation.
- This controller is useful for early bench damping tests, but it is not the final inverted-pendulum LQR controller.

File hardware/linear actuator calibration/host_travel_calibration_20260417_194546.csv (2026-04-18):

speed_steps_s | commanded_relative_steps | start_steps | actual_start_steps | target_steps | actual_position_steps | start_tape_reading_mm | tape_reading_mm | completed | note
400.0 | 6000 | 100 | 100 | 6100 | 6100 | 599 | 35.5 | True
400.0 | 5000 | 100 | 100 | 5100 | 5100 | 599 | 129.5 | True
400.0 | 4000 | 100 | 100 | 4100 | 4100 | 599 | 223.5 | True
400.0 | 3000 | 100 | 100 | 3100 | 3100 | 599 | 317.5 | True
400.0 | 2000 | 100 | 100 | 2100 | 2100 | 599 | 411.5 | True
400.0 | 1000 | 100 | 100 | 1100 | 1100 | 599 | 505 | True

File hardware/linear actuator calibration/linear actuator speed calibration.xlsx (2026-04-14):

400 | pulses per revolution |  | ON OFF OFF | (dip switches 1 -3 )
speed | delay | ms |  |  | dist | 470 | mm | 5000 | steps
24.29442779 | 2400 | 19346
25.35059331 | 2300 | 18540
26.49977447 | 2200 | 17736
27.75973067 | 2100 | 16931
29.14547935 | 2000 | 16126
30.67484663 | 1900 | 15322
32.37583523 | 1800 | 14517
34.27404653 | 1700 | 13713
36.4143488 | 1600 | 12907
38.8333471 | 1500 | 12103
41.60028324 | 1400 | 11298
44.79603507 | 1300 | 10492
48.50861802 | 1200 | 9689
52.91005291 | 1100 | 8883
58.17551677 | 1000 | 8079
64.6136926 | 900 | 7274
72.66542981 | 800 | 6468
82.96557811 | 700 | 5665
96.70781893 | 600 | 4860
115.9062885 | 500 | 4055
144.6153846 | 400 | 3250
192.2290389 | 300 | 2445
286.4107252 | 200 | 1641
301.2820513 | 190 | 1560
317.7822853 | 180 | 1479
336.1945637 | 170 | 1398
356.3305534 | 160 | 1319
379.644588 | 150 | 1238

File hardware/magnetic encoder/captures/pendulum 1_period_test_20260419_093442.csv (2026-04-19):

host_timestamp_s | time_ms | connected | magnet_detected | magnet_too_weak | magnet_too_strong | agc | magnitude | raw_count | unwrapped_count | theta_deg | theta_rad | omega_rad_s
1776609291.001982 | 8459 | True | False | True | False | 255 | 137 | 2052 | 2052 | -0.0879 | -0.001534 | -0.153398
1776609291.017928 | 8469 | True | False | True | False | 255 | 138 | 2050 | 2050 | -0.2637 | -0.004602 | -0.306796
1776609291.022681 | 8479 | True | False | True | False | 255 | 138 | 2051 | 2051 | -0.1758 | -0.003068 | 0.153398
1776609291.029746 | 8489 | True | False | True | False | 255 | 137 | 2053 | 2053 | 0.0 | 0.0 | 0.306796
1776609291.047207 | 8499 | True | False | True | False | 255 | 138 | 2053 | 2053 | 0.0 | 0.0 | 0.0
1776609291.055646 | 8509 | True | False | True | False | 255 | 139 | 2053 | 2053 | 0.0 | 0.0 | 0.0
1776609291.067673 | 8519 | True | False | True | False | 255 | 140 | 2054 | 2054 | 0.0879 | 0.001534 | 0.153398
1776609291.076806 | 8529 | True | False | True | False | 255 | 140 | 2054 | 2054 | 0.0879 | 0.001534 | 0.0
1776609291.082168 | 8539 | True | False | True | False | 255 | 140 | 2055 | 2055 | 0.1758 | 0.003068 | 0.153459
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

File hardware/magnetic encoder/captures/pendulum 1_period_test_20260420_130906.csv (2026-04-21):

host_timestamp_s | time_ms | connected | magnet_detected | magnet_too_weak | magnet_too_strong | agc | magnitude | raw_count | unwrapped_count | theta_deg | theta_rad | omega_rad_s
1776708554.901155 | 9089 | True | False | True | False | 255 | 17 | 1363 | 1363 | -0.4395 | -0.00767 | -0.767297
1776708554.909919 | 9099 | True | False | True | False | 255 | 17 | 1362 | 1362 | -0.5273 | -0.009204 | -0.153337
1776708554.918704 | 9109 | True | False | True | False | 255 | 14 | 1366 | 1366 | -0.1758 | -0.003068 | 0.613838
1776708554.930576 | 9119 | True | False | True | False | 255 | 17 | 1350 | 1350 | -1.582 | -0.027612 | -2.454369
1776708554.938103 | 9129 | True | False | True | False | 255 | 17 | 1352 | 1352 | -1.4062 | -0.024544 | 0.306796
1776708554.949708 | 9139 | True | False | True | False | 255 | 15 | 1344 | 1344 | -2.1094 | -0.036816 | -1.227185
1776708554.959270 | 9149 | True | False | True | False | 255 | 15 | 1337 | 1337 | -2.7246 | -0.047553 | -1.073787
1776708554.971266 | 9159 | True | False | True | False | 255 | 15 | 1332 | 1332 | -3.1641 | -0.055223 | -0.76699
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

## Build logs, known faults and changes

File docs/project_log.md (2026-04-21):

# Project Log

## 2026-04-21

Reorganized the project video assets and updated the top-level demo link to the newest upright-balance video.

Completed:

- Moved the current showcase video into the project media folder:
  - `docs/media/upright_balance_run_2026-04-21.mp4`
- Archived the previous top-level local fallback video into the same media folder:
  - `docs/media/upright_balance_run_2026-04-21_previous.mp4`
- Kept the older April 18 demo video in the same location for historical reference:
  - `docs/media/upright_balance_run_2026-04-18.mp4`
- Updated the top-level README to:
  - point to the new YouTube demo `https://youtu.be/KnxtTf5F7fo`
  - use `docs/media/` as the local fallback video location

Notes:

- The repository video convention is now to keep showcase MP4s under `docs/media/` instead of mixing media files at the repository root.

Next:

- Keep future public/demo videos under `docs/media/` with date-based names so the README can be updated without moving files again.

## 2026-04-21

Added a live upright-control UI for bench tuning and updated the current upright defaults and plotting workflow around that interface.

Completed:

- Added a dedicated upright-control GUI workflow:
  - `python -m software.host.main control-up-ui`
  - `software/host/upright_control_ui.py`
  - `software/host/main.py`
- The new UI now:
  - auto-connects to the current bench COM ports by default
  - homes left and moves to the midpoint on launch
  - provides `Start Automatic Control`, `Zero Encoder`, and `Stop And Exit` buttons
  - plots filtered `theta`, filtered `omega`, and commanded speed live on one chart
  - overlays the current `settle theta` and `settle omega` bands on the plot
  - allows live tuning of `Q`, `R`, deadbands, trigger thresholds, and settle thresholds from sliders
- Changed the current upright default LQR weights to a more aggressive baseline:
  - `q_x = 3`
  - `q_theta = 100`
  - `software/host/pendulum_control.py`
  - `software/host/main.py`
- Changed the current upright settle defaults to a looser disarm condition:
  - `settle_theta = 0.050 rad`
  - `settle_omega = 6.0 deg/s`
  - `settle_samples = 8`
- Updated the upright UI so all omega-facing controls use `deg/s` for display while the controller still works internally in radians.
- Fixed the left plot axis to `-15 deg` to `+15 deg` so the chart stays visually stable during tuning.
- Updated top-level and host-side documentation to mention the UI-based upright workflow:
  - `README.md`
  - `software/host/README.md`

Notes:

- The UI chart now intentionally emphasizes readability over automatic rescaling so settling behavior and threshold overlays are easier to interpret at a glance.
- The settle overlays were switched from the earlier deadband view because the settle thresholds better explain why the controller disarms and stays quiet.

Next:

- Re-test the new `q_x = 3`, `q_theta = 100` baseline against the previous working settings and compare drift, chatter, and recovery margin.
- Decide whether the upright UI should eventually replace the text-based staging loop for most tuning work.

## 2026-04-21

Added upright-control hysteresis so the cart can stop making tiny corrective moves once the pendulum is balanced near upright.

Completed:

- Updated the upright host defaults to require a small but nonzero disturbance before re-arming after a settled upright state:
  - `software/host/pendulum_control.py`
  - `software/host/main.py`
- Kept the existing upright settle thresholds and widened the gap between settle and re-arm behavior so the controller can truly stand down instead of immediately waking back up on jitter.
- Updated host-side documentation to describe the new upright re-arm behavior:
  - `software/host/README.md`
- Updated the top-level README upright run command to match the current default-based working workflow:
  - `README.md`

Notes:

- The prior upright defaults allowed immediate re-arm after disarming, which made low-amplitude residual motion look like a reason to keep chasing the pendulum even after it was effectively balanced.
- The new upright defaults re-arm only after `|theta| > 0.015 rad` or `|theta_dot| > 0.08 rad/s` for `3` consecutive samples.
- The settle condition remains `|theta| < 0.01 rad` and `|theta_dot| < 0.05 rad/s` for `50` consecutive samples, so the controller now has a deliberate hysteresis gap between "stop helping" and "help again."

Next:

- Re-test upright control over longer runs to see whether reduced tail-phase chatter also reduces long-term cart drift.
- If needed, tune the new re-arm thresholds from the latest control CSVs rather than continuing by feel alone.

## 2026-04-21

Reached repeatable successful upright balancing on hardware and updated the top-level project presentation to reflect that milestone.

Completed:

- Saved the latest successful upright-control run and sidecar logs under stable names:
  - `hardware/control experiments/upright/successful_repeatable_upright_balance_20260421_113304.csv`
  - `hardware/control experiments/upright/successful_repeatable_upright_balance_20260421_113304_encoder_samples.csv`
  - `hardware/control experiments/upright/successful_repeatable_upright_balance_20260421_113304_actuator_samples.csv`
  - `hardware/control experiments/upright/successful_repeatable_upright_balance_20260421_113304_limit_samples.csv`
- Recorded the repeatably working upright CLI:
  - `python -m software.host.main --actuator-port COM6 --limits-port COM10 --encoder-port COM8 control-up --pendulum-length-m 0.50 --q-x 1 --q-x-dot 0.1 --q-theta 50 --q-omega 1 --r-input 1`
- Updated the top-level README to:
  - embed the new top-level video `inverted_pendulum.mp4`
  - describe the project as a successful real-hardware upright-control demonstration
  - note the course inspiration from `ASE 381P-3 Optimal Control` with Dr. Bakolas at UT Austin
  - point readers to the saved successful run and the working upright command
- Recorded the current linear actuator microstep-driver DIP switch positions:
  - `1-6 = ON, OFF, OFF, OFF, OFF, OFF`
  - `hardware/linear actuator control/linear_actuator_controller/README.md`

Notes:

- The current success case is now repeatable with the `0.50 m`, `Q = diag([1, 0.1, 50, 1])`, `R = 1` controller settings.
- The top-level README already contains a hardware section, but it is still more of a current setup summary than a formal bill of materials.

Next:

- Add a dedicated hardware bill of materials or parts list if a more explicit procurement/reference document would be useful.
- Preserve the current successful encoder placement, mechanical setup, and wiring details in documentation before making further tuning changes.

## 2026-04-19

Validated the pendulum-1 center-of-mass length with a small-angle free-swing period test and documented the result.

Completed:

- Added a dedicated host-side period-test capture command:
  - `python -m software.host.main --encoder-port COM8 period-test`
  - `software/host/main.py`
  - `software/host/encoder_capture.py`
- Collected a pendulum-1 period-test capture:
  - `hardware/magnetic encoder/captures/pendulum 1_period_test_20260419_093442.csv`
- Added a period-test analysis notebook:
  - `hardware/magnetic encoder/analysis/analyze_pendulum_1_period_test.ipynb`
- Updated the host, modeling, and top-level documentation to record the measurement and its agreement with the first-pass MATLAB LQR parameter.

Notes:

- The pendulum-1 free-swing period test gave an average measured period of about `1.42 s`.
- Under the simple-pendulum assumption, that implies an effective pendulum length of about `0.500 m`.
- The first-pass MATLAB LQR work used `l = 0.510 m`, so the period test agrees well with the original tape-measure estimate and supports keeping that parameter for now.
- The analysis notebook was corrected to estimate the full period from same-sign extrema after an earlier half-period mistake temporarily produced an incorrect `0.125 m` estimate.

Next:

- If the pendulum geometry changes, repeat the same period-test workflow and update the model parameter if needed.
- Keep using `l = 0.510 m` as the current first-pass modeling value unless later hardware changes justify revising it.

## 2026-04-18

Added host-side magnetic encoder capture tooling and collected initial bench data.

Completed:

- Added an interactive encoder capture command:
  - `python -m software.host.main --encoder-port COM8 capture-encoder`
  - `software/host/encoder_capture.py`
- Collected AS5600 free-swing and manual held-angle captures:
  - `hardware/magnetic encoder/captures/encoder_capture_20260418_112254.csv`
  - `hardware/magnetic encoder/captures/encoder_capture_20260418_113008.csv`
  - `hardware/magnetic encoder/captures/encoder_capture_20260418_113607.csv`
  - `hardware/magnetic encoder/captures/encoder_capture_results.md`
- Added and ran a downward-equilibrium LQR simulation for early bench damping tests:
  - `modeling/pendulum_actuator_derivation/scripts/lqr_downward_first_pass.m`
  - `modeling/pendulum_actuator_derivation/results/downward_first_pass/lqr_downward_first_pass_results.md`
  - `modeling/pendulum_actuator_derivation/results/downward_first_pass/LQR_downward_closed_loop_response.fig`
  - `modeling/pendulum_actuator_derivation/results/downward_first_pass/LQR_downward_closed_loop_response.png`

Notes:

- The encoder capture workflow recorded about `100 Hz` data and showed good return-to-zero behavior near the downward resting position.
- Larger manual angle checks showed asymmetric response. A roughly `45 deg` side-to-side test reported about `-47 deg` on one side and about `+89 deg` on the other.
- A likely mechanical cause is that the magnet is currently sitting on the pendulum axle bolt head and may not be flat or centered relative to the AS5600.
- The AS5600 magnetic diagnostics still reported weak-field behavior even while angle data was smooth enough for qualitative testing.
- The downward LQR gain was `K = [0.3162, 0.8139, -0.3088, -0.3479]`, with peak simulated commanded acceleration `0.112 m/s^2` and peak cart displacement `0.027 m`.

Next:

- Design a more dimensionally stable magnet/sensor alignment method for the AS5600.
- Repeat encoder held-angle validation after improving magnet alignment.
- Continue toward the fixed-rate hardware control loop and state-estimation software tasks.

## 2026-04-17

Continued hardware bring-up for the sensing electronics.

Completed:

- Created the mount for the magnetic encoder Arduino:
  - `hardware/cad/stl/arduino mount.stl`
- Built the wire harness for the actuator limit sensors.
- Marked the optical limit sensor reader firmware complete for the current setup.
- Marked the AS5600 magnetic encoder reader firmware complete for the current setup.
- Added first-pass pendulum-actuator modeling notes:
  - `modeling/pendulum_actuator_derivation/README.md`
  - `modeling/pendulum_actuator_derivation/docs/parameters.md`
  - `modeling/pendulum_actuator_derivation/docs/inverted pendulum derivation.pdf`
  - `modeling/pendulum_actuator_derivation/docs/torque_diagram.svg`
- Added and ran an initial MATLAB LQR simulation:
  - `modeling/pendulum_actuator_derivation/scripts/lqr_first_pass.m`
  - `modeling/pendulum_actuator_derivation/results/upright_first_pass/lqr_first_pass_results.md`
  - `modeling/pendulum_actuator_derivation/results/upright_first_pass/LQR_closed_loop_response.fig`
  - `modeling/pendulum_actuator_derivation/results/upright_first_pass/LQR_closed_loop_response.png`
- Added an initial Python host software scaffold:
  - `software/host/README.md`
  - `software/host/requirements.txt`
  - `software/host/main.py`
  - `software/host/serial_worker.py`
  - `software/host/arduino_actuator.py`
  - `software/host/arduino_limits.py`
  - `software/host/arduino_encoder.py`
- Added basic host-side actuator motion commands with limit-sensor checks:
  - `software/host/motion_control.py`
- Organized the updated current bench setup photo:
  - `docs/images/assembled_pendulum_bench_setup_2026-04-17.jpg`

Notes:

- The current sensing firmware remains split across Arduino #2 for the optical limit sensors and Arduino #3 for the AS5600 magnetic encoder.
- The first-pass model treats the pendulum as a point mass with \(l = 0.510\ \text{m}\), measured from the pivot to the rough center of mass of the bob.
- The initial LQR simulation used \(Q = \operatorname{diag}(1,\ 0.1,\ 50,\ 1)\) and \(R = 1\). The computed gain was \(K = [-1.0000,\ -2.0104,\ -29.1450,\ -6.5238]\).
- The initial closed-loop simulation had peak commanded acceleration \(2.543\ \text{m/s}^2\) and peak cart displacement \(0.228\ \text{m}\). With approximately \(0.60\ \text{m}\) total actuator travel, the displacement is within the nominal centered travel range but leaves limited margin.
- The initial host software uses one background serial worker per Arduino interface. The actuator interface includes command helpers, while the limit sensor and encoder interfaces continuously parse the latest streamed sample.
- The Python host monitor was tested with the current bench COM-port assignment: actuator on `COM6`, limit sensors on `COM10`, and encoder on `COM8`. It successfully read live status/data from all three Arduinos, and `Ctrl+C` shut down the monitor as expected.
- The host motion layer uses the measured actuator travel calibration `10.652 steps/mm`, or about `0.093879 mm/step`, and the total travel estimate remains about `600 mm`. Negative motion is assumed to travel toward the left limit, and positive motion toward the right limit.
- A cautious live host motion smoke test worked as expected using `python -m software.host.main --actuator-port COM6 --limits-port COM10 speed 5 --duration 1`.
- Direction signs were confirmed. Positive host speed moves away from the left limit, and negative host speed moves toward the left limit. A negative speed command was correctly refused while the left limit was already active.
- Left homing while already at the left limit correctly set the actuator position estimate to zero, and a subsequent `move-mm 50 --speed-mm-s 10` command moved off the left limit and stopped as expected.
- The interactive host motion shell was tested with `home left 10`, `status`, `move 50 10`, `status`, and `quit` in one continuous serial session. The final status reported `position_steps = 532` and `position_mm = 50.008`.
- After updating the host to disable the actuator driver after completed `home` and `move` commands, the shell workflow was repeated and ended with `enabled = False`, `motion_mode = 0`, `position_steps = 532`, and `position_mm = 50.008`.
- After a right-limit test reported `position_mm` very close to the provisional `600 mm` travel estimate, the host and actuator firmware were adjusted so Arduino #1 only handles raw step and step-rate commands while millimeter conversion remains on the host side. The host now includes a raw `move-steps` command and `steps` shell command for calibration work.
- Arduino #1 raw step commands were verified through the Arduino Serial Monitor after re-uploading the updated firmware. The Python host raw-step shell command was also verified: `steps 100 100` increased `position_steps` from `0` to `100`, and `steps -100 100` returned it to `0`.
- The updated current bench setup photo shows the full actuator rail with the assembled pendulum carriage, limit-sensor hardware, encoder mount, wire harness, and three-Arduino electronics layout.
- Added an interactive host travel calibration routine:
  - `software/host/travel_calibration.py`
- An initial travel-calibration attempt exposed a stale actuator-status issue after homing. The host now waits for Arduino #1 to report `position_steps = 0` after left homing before continuing to the first calibration move. Empty CSV files from the interrupted attempts were not kept.
- Updated the host travel calibration routine so each speed is selected interactively, the 100-step tape reading is confirmed before every move, and completed data is saved after each requested speed set.
- Collected host travel calibration data:
  - `hardware/linear actuator calibration/host_travel_calibration_20260417_194546.csv`
  - `hardware/linear actuator calibration/host_travel_calibration_results.md`
- Averaged the completed calibration rows to set the host default actuator scale to `10.652 steps/mm`.

Next:

- Verify clearances, alignment, range of motion, and mechanical stiffness on the assembled pendulum.
- Add editable CAD source files if available.
- Verify the encoder signal through the installed magnet/shaft geometry.
- Refine physical parameter estimates for the pendulum and actuator.
- Compare first-pass LQR acceleration commands against actuator limits.
- Tune and validate the LQR controller in simulation.
- Bench-test host-side homing and absolute-position moves.

## 2026-04-16

Added initial printable hardware assets and CAD reference material.

Completed:

- Added 3D-printable STL exports under `hardware/cad/stl/`:
  - `hardware/cad/stl/bearing mount.stl`
  - `hardware/cad/stl/encoder mount.stl`
  - `hardware/cad/stl/pendulum hinge.stl`
  - `hardware/cad/stl/weight attachment.stl`
  - `hardware/cad/stl/weight attachment - threaded.stl`
- Added a linear actuator stage hole-pattern reference photo:
  - `hardware/cad/reference/linear actuator stage holes.jpg`
- Updated the README with the current CAD file list and the `hardware/cad/reference/` convention.
- Resolved the local documentation next-step item to add initial CAD/STL files for the printed hardware structure.
- Added a placeholder folder for AS5600 magnetic encoder Arduino example code:
  - `hardware/magnetic encoder/as5600_example/`
- Added AS5600 pendulum angle reader firmware:
  - `hardware/magnetic encoder/pendulum_angle_reader/pendulum_angle_reader.ino`
- Added initial optical limit sensor reader firmware:
  - `hardware/limit sensors/limit_sensor_reader/limit_sensor_reader.ino`
- Added Arduino #1 linear actuator controller firmware:
  - `hardware/linear actuator control/linear_actuator_controller/linear_actuator_controller.ino`
- Organized the current bench setup photo:
  - `docs/images/assembled_pendulum_bench_setup_2026-04-16.jpg`
- Tested the AS5600 magnetic encoder example with Arduino. The encoder connects over I2C and returns smooth angle readings.
- Assembled the pendulum using the 3D printed parts made today.
- Tested both optical actuator limit sensors with Arduino. Brown is wired to `5V`, blue to `GND`, black to the Arduino input, and white is disconnected for the current setup.
- Tested the Arduino #1 linear actuator controller firmware successfully.

Notes:

- Current hardware I/O is split across three Arduinos: Arduino #1 controls actuator motion, Arduino #2 reads the optical limit sensors, and Arduino #3 reads the AS5600 magnetic encoder.
- The new STL files are printable exports. Editable CAD source files still need to be added if they are available.
- The AS5600 example sketch is stored under `hardware/magnetic encoder/as5600_example/AS5600_demo/`.
- The pendulum angle reader streams CSV angle data at `115200` baud and supports Serial commands for zeroing and wrap-tracking reset.
- The limit sensor reader uses brown to Arduino `5V`, blue to `GND`, black as the Arduino input signal, and white disconnected. The two tested limit sensor inputs are Arduino `D2` and `D3`.
- The linear actuator controller uses `D10` for step, `D11` for direction, and `D12` for active-low enable. It supports serial commands for enable, stop, relative moves, signed step rate, and signed calibrated actuator speed.
- The current bench setup photo shows the assembled actuator and pendulum hardware with the in-progress three-Arduino layout.
- During AS5600 testing, the status bits reported `magnet_detected = 0` and `magnet_too_weak = 1` even while angle readings were smooth. The observed diagnostic values included `AGC = 255` and magnitude around `279`, so the magnet-strength flags should be treated as diagnostics until the mechanical magnet setup is finalized.
- VS Code GitHub CLI commands need to be run outside the sandboxed shell to use the Windows keyring credentials.
- GitHub issue #10, `Assemble pendulum with 3D printed parts`, is closed.

Next:

- Verify clearances, alignment, range of motion, and mechanical stiffness on the assembled pendulum.
- Add editable CAD source files if available.
- Verify the encoder signal through the installed magnet/shaft geometry.

## 2026-04-14

Initial project organization and calibration setup.

Completed:

- Created the initial project README.
- Added a `hardware/` folder for hardware-related files.
- Organized linear actuator calibration files under `hardware/linear actuator calibration/`.
- Added the linear actuator speed calibration spreadsheet.
- Added the Arduino sketch used to collect linear actuator calibration data:
  - `hardware/linear actuator calibration/calibrate_linear_actuator/calibrate_linear_actuator.ino`
- Added a Python/Jupyter notebook to extract calibration data and fit the actuator command equation:
  - `hardware/linear actuator calibration/actuator_speed_fit.ipynb`
- Documented the linear actuator calibration procedure:
  - `hardware/linear actuator calibration/calibration_procedure.md`
- Fit the actuator speed-to-delay command equation:

```text
delay = 58399.75215056 / (speed + 0.00022846) - 3.82116746
```

- Updated the README with the calibration files, command equation, and planned hardware/CAD organization.
- Installed and authenticated GitHub CLI.
- Created GitHub milestones:
  - Project Setup
  - Linear Actuator Calibration
  - Hardware Bring-Up
  - Pendulum Sensing
  - System Modeling and LQR
  - Software-Hardware Integration
  - Final Demo and Documentation
- Committed and pushed the initial project setup and calibration files.

Notes:

- 3D-printable STL files should go in `hardware/cad/stl/`.
- Editable CAD source files should go in `hardware/cad/source/`.
- CAD reference photos and measurements should go in `hardware/cad/reference/`.
- PowerShell currently prints a profile script warning because script execution is disabled, but Git and GitHub CLI are working.

Next:

- Create initial GitHub issues under the new milestones.
- Document the current physical hardware setup and wiring.
- Verify the actuator speed-to-delay equation on hardware.
- Decide on the pendulum angle sensing approach.

## 2026-04-18

Downward control tuning reached a usable first-pass baseline on hardware.

Completed:

- Added a host-side `control-down` experiment for the downward pendulum case.
- Added a downward-equilibrium LQR MATLAB script and documented the first-pass gain.
- Added host-side sign handling for actuator command, cart position, and encoder angle conventions.
- Added an `alpha-beta` theta/theta-dot estimator with separate pre-arm and armed tuning.
- Added trigger/disarm logic so the cart stays quiet when the pendulum is still, engages on real perturbations, and returns to zero command after the motion settles.
- Tuned the current baseline around repeated bench tests so the cart can recover from multiple manual perturbations without running away or chattering continuously.

Notes:

- Current best-so-far downward control runs showed the cart returning near center and re-engaging after repeated perturbations.
- Residual oscillation remains after control disarms, but this is now a secondary tuning issue rather than a basic sign or startup-instability problem.
- The current baseline command is:

```text
python -m software.host.main --actuator-port COM6 --limits-port COM10 --encoder-port COM8 control-down --invert-actuator-command --invert-cart-position --period-s 0.02
```

Next:

- Preserve this downward-control baseline in git before making larger changes.
- Revisit low-amplitude residual oscillation and tail-phase overreaction with smaller, targeted adjustments.
- Use the downward case as the host/control baseline before moving on to more ambitious inverted-pendulum work.

## 2026-04-18

Extended the upright-control workflow with documentation, analysis overlays, servo-assisted staging, and a measured actuator speed limit.

Completed:

- Added an upright analysis notebook and overlay plots against the current best run:
  - `hardware/control experiments/analysis/analyze_upright_control.ipynb`
- Updated top-level documentation to feature the upright demo video and current upright-control workflow:
  - `README.md`
  - `docs/media/upright_balance_run_2026-04-18.mp4`
- Updated the host and firmware for Arduino #2 to support a simple latch servo:
  - `hardware/limit sensors/limit_sensor_reader/limit_sensor_reader.ino`
  - `hardware/limit sensors/servo_angle_test/servo_angle_test.ino`
  - `software/host/arduino_limits.py`
- Updated `control-up` to use a staging loop after homing/middle:
  - `p` to hold the pendulum with the servo
  - `g` to release the servo
  - `start` to zero the encoder, release the servo, and begin automatic control
- Added a staging-loop diagnostic that reports time-to-fall past `10 deg` after each servo release.
- Bench-tested the actuator speed ceiling and reduced the upright host default speed clamp to the measured no-stall limit of `315 mm/s`.
- Hardened the serial reader so a malformed encoder line no longer kills the host-side reader thread.

Notes:

- The best upright run still remains the earlier manually staged run at about `6.75 s`; the servo-assisted workflow improved repeatability of the start condition but has not yet improved the best achieved balance duration.
- Recent poor upright runs appear more consistent with startup/release transients or physical actuator limitations than with a sign error or a dramatic observer failure.
- Current upright control remains most sensitive to initial condition, release repeatability, and real actuator authority.

Next:

- Compare servo-assisted starts directly against manual starts to separate release-transient effects from controller limitations.
- Consider mechanical changes that slow the upright dynamics or reduce release disturbance, including pendulum length and latch geometry.
- Use the new staging-loop `g` timing metric to quantify release repeatability before further controller changes.

## 2026-04-19

Moved the host-side pendulum control workflow away from fixed MATLAB-exported gains and toward Python-side LQR synthesis tied directly to the pendulum length and requested cost weights.

Completed:

- Added Python LQR synthesis inside the host controller using the same linearized model structure as the MATLAB first-pass scripts:
  - `software/host/pendulum_control.py`
  - `software/host/requirements.txt`
- Exposed on-demand LQR tuning from the CLI for both `control-down` and `control-up`:
  - `--lqr-mode {python,manual}`
  - `--pendulum-length-m`
  - `--q-x`
  - `--q-x-dot`
  - `--q-theta`
  - `--q-omega`
  - `--r-input`
  - `software/host/main.py`
- Kept compatibility with manual gain entry so hardware runs can still use explicit `K` values when desired.
- Increased the upright default speed clamp from `315 mm/s` to `325 mm/s` for further bench testing:
  - `software/host/main.py`
  - `software/host/pendulum_control.py`
  - `software/host/README.md`
- Added a startup guard that waits for a fresh encoder snapshot after arming so the control loop does not launch on stale pre-zero data:
  - `software/host/pendulum_control.py`
- Updated control CSV logging so every run records the full controller configuration as `config_*` columns:
  - LQR mode
  - pendulum length
  - `Q`, `R`
  - resolved gains
  - estimator settings
  - deadbands, clamps, trigger/disarm settings
  - sign conventions and setup flags
- Updated the upright analysis notebook so it prints the active log path and displays the `config_*` summary clearly near the top:
  - `hardware/control experiments/analysis/analyze_upright_control.ipynb`
- Updated project-facing docs to describe the new Python tuning workflow and self-describing control logs:
  - `README.md`
  - `software/host/README.md`

Notes:

- The host now defaults to computing `K` directly from the pendulum length and chosen `Q`, `R`, which removes the need to round-trip through MATLAB for routine gain changes.
- The default upright and downward Python synthesis settings were chosen to reproduce the earlier first-pass MATLAB gains closely, so the tuning baseline remains continuous with prior work.
- The new `config_*` fields make later notebook analysis much easier because the run settings now travel with the data.

Next:

- Re-test upright control once the encoder and magnet hardware rework is installed.
- Use the logged `config_*` fields to compare successful and failed runs without relying on terminal notes.
- Decide whether to add a hard startup refusal when encoder magnetic diagnostics indicate that the magnet is missing or too weak.

## 2026-04-20

Refined the current bench defaults and documented the actual Arduino wiring used on the encoder and limit/servo boards.

Completed:

- Updated the host default pendulum length for Python LQR synthesis to `0.500 m`:
  - `software/host/pendulum_control.py`
  - `software/host/main.py`
- Increased the upright default acceleration clamp to `30.0 m/s^2` and the upright default speed clamp to `350 mm/s` for further bench testing:
  - `software/host/pendulum_control.py`
  - `software/host/main.py`
  - `software/host/README.md`
- Added an interactive actuator acceleration sweep command for stall testing:
  - `accel-sweep`
  - homes left before each trial
  - ramps to a target speed with a chosen acceleration
  - keeps host-side limit protection active during the test
  - asks whether the motor stalled before continuing
- Documented the actual AS5600-to-Arduino wiring currently used on the bench:
  - `hardware/magnetic encoder/pendulum_angle_reader/README.md`
- Documented the actual Arduino #2 limit-sensor and latch-servo wiring:
  - `hardware/limit sensors/limit_sensor_reader/README.md`
- Updated top-level and host docs to remove stale references to the earlier `325 mm/s` upright default and to reflect the current `0.500 m` host pendulum-length default:
  - `README.md`
  - `software/host/README.md`

Notes:

- Recent upright runs still show that long periods of successful balancing can end abruptly once the cart state drifts far enough that the controller runs out of recoverable margin.
- The newer `config_*` logging remains useful here because each control CSV now records the exact pendulum length, `Q`, `R`, speed clamp, and acceleration clamp used for that run.

Next:

- Use the new `accel-sweep` command to identify a more defensible actuator acceleration limit on hardware.
- Revisit `Q` weighting, especially cart-position weighting, after the actuator authority limits are better characterized.

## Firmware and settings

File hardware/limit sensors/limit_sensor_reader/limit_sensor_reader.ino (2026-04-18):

#include <Servo.h>

// Linear actuator optical limit sensor reader.
//
// Serial commands:
//   h  print the CSV header
//   s  print current sensor state immediately
//   g  release servo to 0 deg
//   p  hold servo at 80 deg
//
// Wiring for the first sensor:
//   brown  -> Arduino 5V
//   blue   -> Arduino GND
//   black  -> Arduino D2
//   white  -> disconnected for now
//
// Wiring for the second sensor:
//   brown  -> Arduino 5V
//   blue   -> Arduino GND
//   black  -> Arduino D3
//   white  -> disconnected for now

const unsigned long SERIAL_BAUD = 115200;
const unsigned long SAMPLE_PERIOD_MS = 20;   // 50 Hz status stream
const unsigned long DEBOUNCE_MS = 5;

// Black signal wires.
const byte LEFT_LIMIT_PIN = 2;
const byte RIGHT_LIMIT_PIN = 3;
const byte SERVO_PIN = 7;

const int SERVO_RELEASE_ANGLE_DEG = 0;
const int SERVO_HOLD_ANGLE_DEG = 80;

// White signal wires. These are disabled for initial testing.
const byte LEFT_LIMIT_COMPLEMENT_PIN = 255;
const byte RIGHT_LIMIT_COMPLEMENT_PIN = 255;

// The tested sensors work with the Arduino internal pullups.
const byte LIMIT_INPUT_MODE = INPUT_PULLUP;

// With the tested sensors, a blocked beam reads active.
const byte LIMIT_ACTIVE_LEVEL = LOW;

const byte UNUSED_PIN = 255;

struct DebouncedInput
{
  byte pin;
  bool rawActive;
  bool stableActive;
  bool previousStableActive;
  unsigned long lastRawChangeMs;
};

DebouncedInput leftLimit = {LEFT_LIMIT_PIN, false, false, false, 0};
DebouncedInput rightLimit = {RIGHT_LIMIT_PIN, false, false, false, 0};
DebouncedInput leftComplement = {LEFT_LIMIT_COMPLEMENT_PIN, false, false, false, 0};
DebouncedInput rightComplement = {RIGHT_LIMIT_COMPLEMENT_PIN, false, false, false, 0};

unsigned long lastStatusMs = 0;
Servo latchServo;
int servoAngleDeg = SERVO_RELEASE_ANGLE_DEG;

void setServoAngle(int angleDeg)
{
  servoAngleDeg = angleDeg;
  latchServo.write(angleDeg);
}

bool pinIsUsed(byte pin)
{
  return pin != UNUSED_PIN;
}

bool readActive(byte pin)
{
  if (!pinIsUsed(pin))
  {
    return false;
  }

  return digitalRead(pin) == LIMIT_ACTIVE_LEVEL;
}

void beginInput(DebouncedInput &input)
{
  if (!pinIsUsed(input.pin))
  {
    return;
  }

  pinMode(input.pin, LIMIT_INPUT_MODE);
  input.rawActive = readActive(input.pin);
  input.stableActive = input.rawActive;
  input.previousStableActive = input.stableActive;
  input.lastRawChangeMs = millis();
}

bool updateInput(DebouncedInput &input, unsigned long nowMs)
{
  if (!pinIsUsed(input.pin))
  {
    return false;
  }

  bool rawActive = readActive(input.pin);
  if (rawActive != input.rawActive)
  {
    input.rawActive = rawActive;
    input.lastRawChangeMs = nowMs;
  }

  input.previousStableActive = input.stableActive;

  if ((nowMs - input.lastRawChangeMs) >= DEBOUNCE_MS)
  {
    input.stableActive = input.rawActive;
  }

  return input.stableActive != input.previousStableActive;
}

bool isComplementConsistent(const DebouncedInput &mainInput, const DebouncedInput &complementInput)
{
  if (!pinIsUsed(complementInput.pin))
  {
    return true;
  }

  return mainInput.stableActive != complementInput.stableActive;
}

void printHeader()
{
  Serial.println("time_ms,left_limit,right_limit,left_complement,right_complement,left_pair_ok,right_pair_ok,any_limit,servo_angle_deg");
}

void printState()
{
  bool leftPairOk = isComplementConsistent(leftLimit, leftComplement);
  bool rightPairOk = isComplementConsistent(rightLimit, rightComplement);
  bool anyLimit = leftLimit.stableActive || rightLimit.stableActive;

  Serial.print(millis());
  Serial.print(",");
  Serial.print(leftLimit.stableActive);
  Serial.print(",");
  Serial.print(rightLimit.stableActive);
  Serial.print(",");
  Serial.print(pinIsUsed(leftComplement.pin) ? leftComplement.stableActive : 0);
  Serial.print(",");
  Serial.print(pinIsUsed(rightComplement.pin) ? rightComplement.stableActive : 0);
  Serial.print(",");
  Serial.print(leftPairOk);
  Serial.print(",");
  Serial.print(rightPairOk);
  Serial.print(",");
  Serial.print(anyLimit);
  Serial.print(",");
  Serial.println(servoAngleDeg);
}

void printEvent(const char *name, bool active)
{
  Serial.print("# event,");
  Serial.print(millis());
  Serial.print(",");
  Serial.print(name);
  Serial.print(",");
  Serial.println(active ? "active" : "inactive");
}

void handleSerialCommands()
{
  while (Serial.available() > 0)
  {
    char command = Serial.read();

    if (command == 'h' || command == 'H')
    {
      printHeader();
    }
    else if (command == 's' || command == 'S')
    {
      printState();
    }
    else if (command == 'g' || command == 'G')
    {
      setServoAngle(SERVO_RELEASE_ANGLE_DEG);
      Serial.println("# servo_released");
    }
    else if (command == 'p' || command == 'P')
    {
      setServoAngle(SERVO_HOLD_ANGLE_DEG);
      Serial.println("# servo_hold");
    }
  }
}

void setup()
{
  Serial.begin(SERIAL_BAUD);

  beginInput(leftLimit);
  beginInput(rightLimit);
  beginInput(leftComplement);
  beginInput(rightComplement);
  latchServo.attach(SERVO_PIN);
  setServoAngle(SERVO_RELEASE_ANGLE_DEG);

  Serial.println("# limit_sensor_reader");
  Serial.println("# Send 'h' to print the CSV header, 's' to print the current state, 'g' to release the servo, or 'p' to hold the servo.");
  printHeader();
}

void loop()
{
  unsigned long nowMs = millis();

  handleSerialCommands();

  if (updateInput(leftLimit, nowMs))
  {
    printEvent("left_limit", leftLimit.stableActive);
  }

  if (updateInput(rightLimit, nowMs))
  {
    printEvent("right_limit", rightLimit.stableActive);
  }

  updateInput(leftComplement, nowMs);
  updateInput(rightComplement, nowMs);

  if ((nowMs - lastStatusMs) >= SAMPLE_PERIOD_MS)
  {
    lastStatusMs = nowMs;
    printState();
  }
}

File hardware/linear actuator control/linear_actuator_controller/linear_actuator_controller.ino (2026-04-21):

#include <math.h>
#include <stdlib.h>
#include <string.h>

// Arduino #1 linear actuator stepper controller.
//
// Driver wiring:
//   STEP -> Arduino D10
//   DIR  -> Arduino D11
//   ENA  -> Arduino D12
//
// Serial commands end with a newline:
//   h                         print help
//   ?                         print status
//   e 1                       enable driver
//   e 0                       disable driver
//   x                         stop motion immediately
//   p <steps>                 set current position estimate
//   m <steps> <delay_us>      relative move by step count
//   r <steps_per_second>      continuous signed step-rate command

const byte STEP_PIN = 10;
const byte DIR_PIN = 11;
const byte ENA_PIN = 12;

const byte ENABLE_ACTIVE_LEVEL = LOW;
const byte ENABLE_INACTIVE_LEVEL = HIGH;
const byte DIR_POSITIVE_LEVEL = HIGH;
const byte DIR_NEGATIVE_LEVEL = LOW;

const unsigned long SERIAL_BAUD = 115200;
const unsigned long STATUS_PERIOD_MS = 20;
const unsigned int MIN_STEP_DELAY_US = 10;
const unsigned int MAX_STEP_DELAY_US = 10000;

enum MotionMode
{
  MOTION_IDLE,
  MOTION_RELATIVE_MOVE,
  MOTION_CONTINUOUS
};

MotionMode motionMode = MOTION_IDLE;

bool driverEnabled = false;
bool stepPinHigh = false;
bool completeMoveAfterPulse = false;
int motionDirection = 1;

long positionSteps = 0;
long remainingMoveSteps = 0;

unsigned int stepDelayUs = 1000;
unsigned long lastStepToggleUs = 0;
unsigned long lastStatusMs = 0;

char commandBuffer[96];
byte commandIndex = 0;

void setDriverEnabled(bool enabled)
{
  driverEnabled = enabled;
  digitalWrite(ENA_PIN, enabled ? ENABLE_ACTIVE_LEVEL : ENABLE_INACTIVE_LEVEL);
}

void setDirection(int direction)
{
  motionDirection = (direction >= 0) ? 1 : -1;
  digitalWrite(DIR_PIN, motionDirection > 0 ? DIR_POSITIVE_LEVEL : DIR_NEGATIVE_LEVEL);
}

void forceStepLow()
{
  stepPinHigh = false;
  digitalWrite(STEP_PIN, LOW);
}

void stopMotion()
{
  motionMode = MOTION_IDLE;
  remainingMoveSteps = 0;
  completeMoveAfterPulse = false;
  forceStepLow();
}

unsigned int clampDelayUs(long delayUs)
{
  if (delayUs < MIN_STEP_DELAY_US)
  {
    return MIN_STEP_DELAY_US;
  }

  if (delayUs > MAX_STEP_DELAY_US)
  {
    return MAX_STEP_DELAY_US;
  }

  return (unsigned int)delayUs;
}

unsigned int delayFromStepRate(float stepsPerSecond)
{
  float absRate = fabs(stepsPerSecond);

  if (absRate <= 0.0f)
  {
    return MAX_STEP_DELAY_US;
  }

  float delayUs = 500000.0f / absRate;
  return clampDelayUs((long)(delayUs + 0.5f));
}

void beginRelativeMove(long steps, unsigned int delayUs)
{
  if (steps == 0)
  {
    stopMotion();
    return;
  }

  setDirection(steps > 0 ? 1 : -1);
  stepDelayUs = clampDelayUs(delayUs);
  remainingMoveSteps = labs(steps);
  completeMoveAfterPulse = false;
  motionMode = MOTION_RELATIVE_MOVE;
  forceStepLow();
  lastStepToggleUs = micros();
  setDriverEnabled(true);
}

void beginContinuousStepRate(float stepsPerSecond)
{
  if (stepsPerSecond == 0.0f)
  {
    stopMotion();
    return;
  }

  setDirection(stepsPerSecond > 0.0f ? 1 : -1);
  stepDelayUs = delayFromStepRate(stepsPerSecond);
  completeMoveAfterPulse = false;
  motionMode = MOTION_CONTINUOUS;
  forceStepLow();
  lastStepToggleUs = micros();
  setDriverEnabled(true);
}

void printHelp()
{
  Serial.println("# linear_actuator_controller");
  Serial.println("# Commands:");
  Serial.println("# h                         print help");
  Serial.println("# ?                         print status");
  Serial.println("# e 1                       enable driver");
  Serial.println("# e 0                       disable driver");
  Serial.println("# x                         stop motion immediately");
  Serial.println("# p <steps>                 set current position estimate");
  Serial.println("# m <steps> <delay_us>      relative move by step count");
  Serial.println("# r <steps_per_second>      continuous signed step-rate command");
}

void printStatus()
{
  Serial.print("status,");
  Serial.print(millis());
  Serial.print(",");
  Serial.print(driverEnabled);
  Serial.print(",");
  Serial.print(motionMode);
  Serial.print(",");
  Serial.print(positionSteps);
  Serial.print(",");
  Serial.print(remainingMoveSteps);
  Serial.print(",");
  Serial.print(motionDirection);
  Serial.print(",");
  Serial.println(stepDelayUs);
}

void printStatusHeader()
{
  Serial.println("status,time_ms,enabled,motion_mode,position_steps,remaining_move_steps,direction,step_delay_us");
}

void printAck(const char *message)
{
  Serial.print("ack,");
  Serial.println(message);
}

void printError(const char *message)
{
  Serial.print("error,");
  Serial.println(message);
}

void executeCommand(char *line)
{
  char *command = strtok(line, " ,\t\r\n");

  if (command == NULL)
  {
    return;
  }

  if (strcmp(command, "h") == 0 || strcmp(command, "H") == 0)
  {
    printHelp();
    return;
  }

  if (strcmp(command, "?") == 0)
  {
    printStatusHeader();
    printStatus();
    return;
  }

  if (strcmp(command, "e") == 0 || strcmp(command, "E") == 0)
  {
    char *enabledArg = strtok(NULL, " ,\t\r\n");
    if (enabledArg == NULL)
    {
      printError("missing_enable_value");
      return;
    }

    bool enabled = atoi(enabledArg) != 0;
    if (!enabled)
    {
      stopMotion();
    }

    setDriverEnabled(enabled);
    printAck(enabled ? "enabled" : "disabled");
    return;
  }

  if (strcmp(command, "x") == 0 || strcmp(command, "X") == 0)
  {
    stopMotion();
    printAck("stopped");
    return;
  }

  if (strcmp(command, "p") == 0 || strcmp(command, "P") == 0)
  {
    char *positionArg = strtok(NULL, " ,\t\r\n");
    if (positionArg == NULL)
    {
      printError("missing_position_steps");
      return;
    }

    positionSteps = atol(positionArg);
    printAck("position_set");
    return;
  }

  if (strcmp(command, "m") == 0 || strcmp(command, "M") == 0)
  {
    char *stepsArg = strtok(NULL, " ,\t\r\n");
    char *delayArg = strtok(NULL, " ,\t\r\n");
    if (stepsArg == NULL || delayArg == NULL)
    {
      printError("usage_m_steps_delay_us");
      return;
    }

    beginRelativeMove(atol(stepsArg), clampDelayUs(atol(delayArg)));
    printAck("move_started");
    return;
  }

  if (strcmp(command, "r") == 0 || strcmp(command, "R") == 0)
  {
    char *rateArg = strtok(NULL, " ,\t\r\n");
    if (rateArg == NULL)
    {
      printError("missing_steps_per_second");
      return;
    }

    beginContinuousStepRate(atof(rateArg));
    printAck("step_rate_started");
    return;
  }

  printError("unknown_command");
}
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

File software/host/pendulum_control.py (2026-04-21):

from __future__ import annotations

import csv
from dataclasses import dataclass, fields, replace
from datetime import datetime
from pathlib import Path
from threading import Event, Thread
from time import monotonic, sleep
from typing import Callable

import numpy as np
from scipy.linalg import solve_continuous_are

from .arduino_actuator import ActuatorController
from .arduino_encoder import EncoderReader
from .arduino_limits import LimitSensorReader
from .motion_control import MotionConfig, MotionController
from .serial_worker import SerialSnapshot


@dataclass(frozen=True)
class PendulumControlConfig:
    period_s: float = 0.05
    lqr_mode: str = "python"
    pendulum_length_m: float = 0.500
    lqr_q_x: float = 1.0
    lqr_q_x_dot: float = 0.1
    lqr_q_theta: float = 5.0
    lqr_q_theta_dot: float = 1.0
    lqr_r_input: float = 10.0
    lqr_x_gain: float = 0.3162
    lqr_x_dot_gain: float = 0.8139
    lqr_theta_gain: float = -0.3088
    lqr_theta_dot_gain: float = -0.3479
    center_gain_per_s: float = 0.0
    estimator: str = "alpha-beta"
    theta_alpha: float = 0.35
    theta_beta: float = 0.04
    max_theta_residual_rad: float = 0.01
    armed_theta_alpha: float = 0.40
    armed_theta_beta: float = 0.06
    armed_max_theta_residual_rad: float = 0.025
    theta_filter_alpha: float = 0.25
    theta_dot_filter_alpha: float = 0.20
    max_theta_rate_rad_s: float = 3.0
    theta_deadband_rad: float = 0.003
    theta_dot_deadband_rad_s: float = 0.10
    acceleration_deadband_m_s2: float = 0.005
    control_trigger_theta_rad: float = 0.045
    control_trigger_theta_dot_rad_s: float = 0.30
    control_trigger_samples: int = 2
    settle_theta_rad: float = 0.03
    settle_theta_dot_rad_s: float = 0.15
    settle_samples: int = 25
    settle_raw_theta_rad: float = 0.03
    settle_theta_residual_rad: float = 0.02
    settle_command_speed_mm_s: float = 25.0
    velocity_leak_per_s: float = 0.0
    max_acceleration_m_s2: float = 0.5
    max_speed_mm_s: float = 150.0
    max_abs_theta_rad: float = 0.35
    actuator_command_sign: float = 1.0
    cart_position_sign: float = 1.0
    encoder_angle_sign: float = 1.0
    zero_encoder_on_start: bool = True
    home_before_start: bool = True
    move_middle_before_start: bool = True
    home_speed_mm_s: float = 50.0
    middle_speed_mm_s: float = 50.0


@dataclass(frozen=True)
class DownwardControlConfig(PendulumControlConfig):
    pass


@dataclass(frozen=True)
class UprightControlConfig(PendulumControlConfig):
    period_s: float = 0.01
    lqr_q_x: float = 3.0
    lqr_q_theta: float = 100.0
    lqr_r_input: float = 1.0
    lqr_x_gain: float = -1.0
    lqr_x_dot_gain: float = -2.0104
    lqr_theta_gain: float = -29.1450
    lqr_theta_dot_gain: float = -6.5238
    armed_theta_alpha: float = 0.40
    armed_theta_beta: float = 0.06
    control_trigger_theta_rad: float = 0.015
    control_trigger_theta_dot_rad_s: float = 0.08
    control_trigger_samples: int = 3
    settle_theta_rad: float = 0.05
    settle_theta_dot_rad_s: float = 0.10471975511965977
    settle_samples: int = 8
    settle_raw_theta_rad: float = 0.01
    settle_theta_residual_rad: float = 0.005
    settle_command_speed_mm_s: float = 10.0
    max_acceleration_m_s2: float = 30.0
    max_speed_mm_s: float = 350.0


CONTROL_FIELDS = [
    "host_elapsed_s",
    "host_timestamp_s",
    "encoder_time_ms",
    "theta_deg",
    "theta_rad",
    "omega_rad_s",
    "filtered_theta_rad",
    "filtered_theta_dot_rad_s",
    "theta_residual_rad",
    "control_x_m",
    "control_x_dot_m_s",
    "control_theta_rad",
    "control_theta_dot_rad_s",
    "control_armed",
    "trigger_sample_count",
    "settle_sample_count",
    "actuator_command_sign",
    "cart_position_sign",
    "encoder_angle_sign",
    "raw_count",
    "filtered_count",
    "unwrapped_count",
    "connected",
    "magnet_detected",
    "magnet_too_weak",
    "magnet_too_strong",
    "agc",
    "magnitude",
    "actuator_time_ms",
    "position_steps",
    "position_mm",
    "motion_mode",
    "enabled",
    "left_limit",
    "right_limit",
    "any_limit",
    "command_speed_mm_s",
    "command_step_rate_s",
    "command_acceleration_m_s2",
    "stop_reason",
]

CONFIG_LOG_FIELDS = [f"config_{field.name}" for field in fields(UprightControlConfig)]


def default_output_path(prefix: str = "downward_control", subdir: str = "downward") -> Path:
    timestamp = datetime.now().strftime("%Y%m%d_%H%M%S")
    return Path("hardware") / "control experiments" / subdir / f"{prefix}_{timestamp}.csv"


def run_downward_control(
    actuator: ActuatorController,
    limits: LimitSensorReader,
    encoder: EncoderReader,
    motion: MotionController,
    motion_config: MotionConfig,
    control_config: PendulumControlConfig,
    output_path: Path | None = None,
    output_prefix: str = "downward_control",
    output_subdir: str = "downward",
    experiment_name: str = "Downward pendulum control experiment",
    start_instruction: str = "Start with the cart near center and the pendulum hanging downward and motionless.",
    start_prompt: str = "Let the pendulum hang downward and motionless, then press Enter to zero the encoder and arm automatic control...",
    lqr_equilibrium: str = "downward",
    pre_setup_sequence: Callable[[LimitSensorReader], None] | None = None,
    startup_sequence: Callable[[LimitSensorReader, EncoderReader, PendulumControlConfig], None] | None = None,
) -> Path:
    control_config = resolve_lqr_config(control_config, equilibrium=lqr_equilibrium)
    output_path = output_path or default_output_path(output_prefix, output_subdir)
    output_path.parent.mkdir(parents=True, exist_ok=True)

    stop_event = Event()
    stop_reason = "operator_stop"
    rows: list[dict[str, object]] = []
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

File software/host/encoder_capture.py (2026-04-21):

from __future__ import annotations

import csv
from datetime import datetime
from dataclasses import dataclass
from pathlib import Path
from time import monotonic, sleep
from typing import Callable

from .arduino_encoder import EncoderReader
from .serial_worker import SerialSnapshot


ENCODER_FIELDS = [
    "time_ms",
    "connected",
    "magnet_detected",
    "magnet_too_weak",
    "magnet_too_strong",
    "agc",
    "magnitude",
    "raw_count",
    "filtered_count",
    "unwrapped_count",
    "theta_deg",
    "theta_rad",
    "omega_rad_s",
]


def default_output_path() -> Path:
    timestamp = datetime.now().strftime("%Y%m%d_%H%M%S")
    return Path("hardware") / "magnetic encoder" / "captures" / f"encoder_capture_{timestamp}.csv"


def default_period_test_output_path() -> Path:
    timestamp = datetime.now().strftime("%Y%m%d_%H%M%S")
    return Path("hardware") / "magnetic encoder" / "captures" / f"pendulum 1_period_test_{timestamp}.csv"


@dataclass(frozen=True)
class CaptureSessionConfig:
    title: str
    ready_message: str
    zero_message: str
    keep_zero_message: str
    recording_message: str
    output_path_factory: Callable[[], Path]


GENERIC_CAPTURE_CONFIG = CaptureSessionConfig(
    title="Pendulum encoder capture",
    ready_message="Start with the pendulum hanging downward and motionless.",
    zero_message="The current encoder angle will be zeroed immediately before recording.",
    keep_zero_message="The encoder will keep its current zero.",
    recording_message="Recording. Displace and release the pendulum, then let it swing to rest.",
    output_path_factory=default_output_path,
)


PERIOD_TEST_CAPTURE_CONFIG = CaptureSessionConfig(
    title="Pendulum period test capture",
    ready_message="Start with the pendulum hanging downward and motionless at its small-angle equilibrium.",
    zero_message="The current encoder angle will be zeroed immediately before recording so the resting position is near zero.",
    keep_zero_message="The encoder will keep its current zero.",
    recording_message="Recording. Displace the pendulum by a small angle, release it, and let it swing freely for several cycles before stopping.",
    output_path_factory=default_period_test_output_path,
)


def run_encoder_capture(
    encoder: EncoderReader,
    output_path: Path | None = None,
    zero_on_start: bool = True,
    session: CaptureSessionConfig = GENERIC_CAPTURE_CONFIG,
) -> Path:
    output_path = output_path or session.output_path_factory()
    output_path.parent.mkdir(parents=True, exist_ok=True)

    print(session.title)
    print(f"Output file: {output_path}")
    print(session.ready_message)
    if zero_on_start:
        print(session.zero_message)
    else:
        print(session.keep_zero_message)

    input("Press Enter when you are ready to start recording...")

    if zero_on_start:
        encoder.zero_current_position()
        sleep(0.2)

    encoder.clear_snapshots()
    start_monotonic_s = monotonic()
    print(session.recording_message)

    try:
        input("Press Enter to stop recording...")
    except KeyboardInterrupt:
        print("\nCapture interrupted. Writing samples collected so far.")

    stop_monotonic_s = monotonic()
    snapshots = encoder.drain_snapshots()
    write_snapshots(output_path, snapshots)

    duration_s = max(0.0, stop_monotonic_s - start_monotonic_s)
    sample_rate = len(snapshots) / duration_s if duration_s > 0.0 else 0.0
    print(f"Wrote {len(snapshots)} encoder rows to {output_path}")
    print(f"Capture duration: {duration_s:.3f} s")
    print(f"Average captured sample rate: {sample_rate:.2f} Hz")

    return output_path


def run_period_test_capture(encoder: EncoderReader, output_path: Path | None = None, zero_on_start: bool = True) -> Path:
    return run_encoder_capture(
        encoder,
        output_path=output_path,
        zero_on_start=zero_on_start,
        session=PERIOD_TEST_CAPTURE_CONFIG,
    )


def write_snapshots(output_path: Path, snapshots: list[SerialSnapshot]) -> None:
    fieldnames = ["host_timestamp_s", *ENCODER_FIELDS]

    with output_path.open("w", newline="", encoding="utf-8") as handle:
        writer = csv.DictWriter(handle, fieldnames=fieldnames)
        writer.writeheader()

        for snapshot in snapshots:
            row = {"host_timestamp_s": f"{snapshot.timestamp_s:.6f}"}
            row.update({field: snapshot.data[field] for field in ENCODER_FIELDS})
            writer.writerow(row)

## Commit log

2026-04-14 Add pendulum project setup and actuator calibration
    [linear actuator speed calibration.xlsx]
2026-04-14 Document actuator calibration procedure
2026-04-14 Add calibration setup photo
2026-04-16 Add initial printable CAD assets
    [bearing mount.stl, encoder mount.stl, pendulum hinge.stl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]
2026-04-16 Add AS5600 angle reader firmware
    [weight attachment - threaded.stl]
2026-04-16 Document pendulum assembly
2026-04-16 Add actuator limit sensor reader
2026-04-16 Add linear actuator controller firmware
2026-04-17 Document sensing hardware bring-up
    [arduino mount.stl]
2026-04-17 Add host-side actuator motion commands
2026-04-17 Move actuator unit conversion to host
2026-04-17 Add interactive actuator travel calibration
2026-04-18 Calibrate host actuator travel scale
    [host_travel_calibration_20260417_194546.csv]
2026-04-18 Add actuator midpoint command
2026-04-18 Add encoder capture workflow and results
    [encoder_capture_20260418_112254.csv, encoder_capture_20260418_113008.csv, encoder_capture_20260418_113607.csv]
2026-04-18 Add upright servo staging workflow and actuator limit docs
2026-04-19 Add pendulum period test workflow and validation docs
    [pendulum 1_period_test_20260419_093442.csv]
2026-04-19 Reorganize modeling assets and add LQR sweep outputs
    [lqr_upright_length_qr_sweep_summary.csv]
2026-04-20 Add gen 2 pendulum CAD files
    [arduino mount.f3d, encoder mount.f3d, encoder mount.stl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]
2026-04-21 Update bench control defaults and wiring docs
2026-04-21 Document successful upright balancing and control updates
    [encoder stage X.stl, encoder stage Y.stl, encoder stage Z.stl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]
